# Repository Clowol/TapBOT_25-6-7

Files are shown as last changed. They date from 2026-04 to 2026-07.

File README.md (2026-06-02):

<!--  -->
<div align="center">

# TapSpingRobot-robotArm

</div>

<div align="center">

<span style="font-size:10px;opacity:0.6;">
Open-source implementation for kinematics, control, simulation and modeling of robotic manipulators</br>
</span>

</div>

--- --- ---

<div align="center">

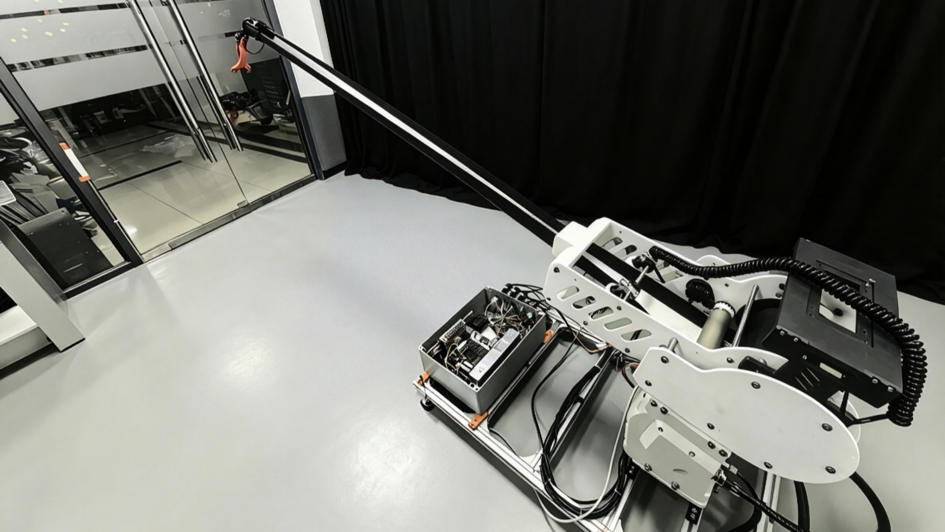
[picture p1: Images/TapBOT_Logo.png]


    
 

</div>
<!-- <p align="center">
<a href="#项目简介">简介</a> •
<a href="#核心功能">功能</a> •
<a href="#项目结构">结构</a> •<a href="#快速开始">快速开始</a> •<a href="#论文成果">论文</a> •<a href="#环境依赖">环境</a></p>
</div> -->

---

## 📖 Project Introduction / 项目简介
This repository contains the complete source code, models, simulation environments and experimental data corresponding to the author’s academic paper and master’s thesis. It focuses on robot arm modeling, motion planning, control algorithms and verification.

<p style="font-size:8px;opacity:0.8;">
本仓库完整收录了作者**小论文**与**硕士学位论文**相关的全部代码、机械臂模型、仿真环境与实验数据，聚焦于机械臂建模、轨迹规划、控制算法与实验验证，同时具备学术价值与工程实用性。
</p>

---

## 🎯 Main Functions / 主要功能
Forward & inverse kinematics, trajectory planning, dynamic modeling, motion control, obstacle avoidance, robot simulation and experimental result visualization.
<p style="font-size:8px;opacity:0.9;">
- 正/逆运动学求解
- 轨迹规划算法实现
- 动力学建模与参数辨识
- 运动控制与优化算法
- 避障与路径规划
- 机器人仿真环境搭建
- 实验曲线与结果可视化
</p>

---

## 📁 Project Structure / 项目结构
'
|--TapROT_26/
| |
| |-- BOM/ 
| |-- Installation Guide
| |-- paper/                 
| |-- Code/
| |-- TapSpingROT_Model/
| |-- TapSpingROT_STL/
| |-- TapSpingROT_URDF/
| |-- README.md
'

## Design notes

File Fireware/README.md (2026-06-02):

```text
--------------------------------------------------------------------
---------------------           科研项目		  -------------------
--------------------------------------------------------------------
```
# 机械臂硬件控制项目

## 1. 项目简介

本项目基于 **STM32F107（Cortex-M3 内核）微控制器**，使用 **Keil uVision（ARMCC）** 作为开发与编译环境，实现一套面向科研与工程验证的 **手动控制（Manual Operation）模式嵌入式系统**。

STM32F107 属于 **Connectivity Line**，片上集成 **CAN / USB OTG / Ethernet / 多路 USART / DMA** 等外设，适合用于：

* 🧪 控制系统与通信协议科研实验
* 🔧 多外设协同控制与实时性验证
* 📚 STM32F1 Connectivity Line 架构学习与工程复现

本仓库已按 **科研级工程规范** 进行整理，适合作为：

* 硕士阶段实验工程仓库
* STM32F107 + Keil 项目模板

-----------------------------------------------------------------------------------------------------

## 2. 硬件与开发环境

| 项目  		| 说明 						|
| ---- 		| --- |
| MCU 		| **STM32F107VC / STM32F107RC（Connectivity Line）** 	|
| 内核  		| ARM Cortex-M3 					|
| 主频 		| 72 MHz 					|
| IDE 		| Keil uVision 5 					|
| 编译器  		| ARMCC / ARM Compiler 							|
| 操作系统 	| Windows  11 							|
| 调试器  		| ST-Link 							|

> ⚠️ **注意**：STM32F107 具有专用启动文件与外设映射，请勿与 F103/F105 混用。

-----------------------------------------------------------------------------------------------------
## 3. 工程目录结构（F107 向科研分层）

```text
MaunalOperation_mode/
├── CMSIS/ # ARM CMSIS 内核与 STM32F107 设备支持
├── FWlib/ # STM32F10x StdPeriph Library（含 F107）
├── Hardware/ # 板级支持包（BSP，强相关硬件）
│ ├── can/ # CAN 通信相关驱动（F107 核心外设）
│ ├── usart/ # 串口通信
│ ├── adc/ # 模拟量采集
│ └── motor/ # 电机/执行器控制
├── System/ # 系统层（时钟/中断/延时/调试接口）
├── User/ # 应用层（控制逻辑 / 状态机）
├── Project/ # Keil 工程文件
│ └── maunaloperation.uvprojx
├── .gitignore # Keil + STM32F107 Git 忽略规则
├── README.md # 项目说明文档
└── keilkill.bat # Keil 临时文件清理脚本（可选）
```

-----------------------------------------------------------------------------------------------------

## 4. 启动文件与系统配置（关键）

### 4.1 启动文件
本工程使用 **STM32F107 专用启动文件**，位于：

```text
CMSIS/DeviceSupport/startup/startup_stm32f10x_cl.s
```

**请确认**：
	* 启动文件为 **Connectivity Line（cl）** 版本
	* 与 MCU 型号（Flash/RAM 大小）匹配

### 4.2 系统时钟配置
	* 外部晶振：8 MHz（常见）
	* 系统主频：72 MHz
	* 时钟初始化位于：
		System/system_stm32f10x.c

	> ⚠️ 修改外部晶振或 PLL 参数时，请同步检查 CAN / USB / Ethernet 时钟配置。

--------------------

## 5. 编译、下载与调试
### 5.1 打开工程

```text
Project/maunaloperation.uvprojx
```

### 5.2 编译
* 编译输出位于：

```text
Objects/
```
> 编译产物 **不纳入 Git 管理**

### 5.3 下载与调试
* 调试接口：SWD / JTAG
* 支持调试器：ST-Link / J-Link

> Debug 相关文件（`.dbgconf`）未纳入版本管理

-----------------------------------------------------------------------------------------------------

## 6. Git 版本管理规范

### 6.1 忽略规则说明

已通过  .gitignore忽略：
* Keil 用户文件：`*.uvoptx` / `*.uvguix.*`
* 编译产物：`Objects/` / `Listings/` / `*.axf` / `*.hex`
* 调试配置：`*.dbgconf`

### 6.2 提交规范（推荐）

```text
feat: 新增外设或功能模块
fix: 修复硬件/驱动问题
exp: 实验性修改
refactor: 结构重构
cleanup: 工程整理（无功能改动）
```

示例：

```bash
git commit -m "feat: add STM32F107 CAN manual control"
```

-----------------------------------------------------------------------------------------------------

## 7. 硬件 使用注意事项

* ⚠️ CAN / USB / Ethernet 需正确配置时钟源
* ⚠️ 不同封装（RC/VC）Flash/RAM 不同
* ⚠️ StdPeriph 库版本需与启动文件一致

-----------------------------------------------------------------------------------------------------

## 9. 作者说明

* 作者：Clomol
* 研究方向：嵌入式系统 / 控制系统 / STM32 通信与驱动

```text
--------------------------------------------------------------------
---------------------           科研项目		  -------------------
--------------------------------------------------------------------
```

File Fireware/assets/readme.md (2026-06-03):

# TapBOT 下位机通讯协议手册

---

## 一、系统控制源

当前有两个控制源：

### 1. 遥控器模式 `RMT_MODE`

- 遥控器从 **USART3** 输入。
- `Rmt_CommProc()` 从 USART3 环形缓冲区解析遥控帧。
- `RmtDataExchange()` 将遥控通道量转换为工程控制量：
  - `RmtGearValue`：M8010 伸缩速度输入，范围约 **-50 ~ +50**
  - `Rmt_Y1_Value`：舵机 1~3 速度输入，范围约 **-50 ~ +50**
  - `Rmt_PTZ_UpDown` / `Rmt_PTZ_LftRgt`：云台方向
  - `RmtClutchStartStop`：电磁阀/离合控制
- `ControlDispatcher_Update()` 将遥控变量整理成统一的 `g_ctrl_cmd`。
- 执行层读取 `g_ctrl_cmd` 控制 M8010、云台、副板舵机。

### 2. 上位机模式 `UP_MODE`

- 上位机从 **USART2** 输入。
- `ROS2_CommProc()` 实际调用 `Upper_CommProc()`。
- `Upper_CommProc()` 解析 **0xA5 自定义协议帧**。
- 解析成功后调用：`ControlDispatcher_OnUpperPacketReceived(cmd_id, payload, len)`

- 控制分配器根据 `cmd_id` 分发到：

| 功能 | 说明 |
|---|---|
| M8010 CAN 控制 | 电机速度/位置控制 |
| 舵机位置控制 | 舵机 1~3 位置闭环 |
| 云台速度/角度控制 | PTZ 控制 |
| 控制源切换/心跳 | 模式切换与保活 |

> **上位机要真正接管，需要满足两个条件：**
>
> 1. 遥控/系统模式变量 `g_RmtUpManCtrlMode == UP_MODE`
> 2. 上位机心跳未超时

上位机超时时间：

```c
CTRL_UPPER_TIMEOUT_TICKS_10MS = 50  // 约 500 ms
```

> **建议**：上位机以 **50~100 ms** 周期发送心跳 `0x7F`。

---

## 二、主循环调度

主循环核心流程：

```c
while(1)
{
    ROS2_CommProc();     // USART2 上位机协议解析
    FunctionProce();     // 遥控、串口、主副板接收处理

    if(flag10ms)   Function_10ms();
    if(cnt30ms)    Function_30ms();
    if(cnt50ms)    Function_50ms();
    if(cnt100ms)   Function_100ms();
    if(cnt500ms)   Function_500ms();
}
```

### 周期任务说明

| 周期 | 函数 | 作用 |
|---|---|---|
| **10ms** | `Function_10ms()` | `ControlDispatcher_Update()` + `SubBoard_LinkTick10ms()` |
| **30ms** | `Function_30ms()` | `YushuMotor_ControlProc()` + M8010 控制输出 |
| **50ms** | `Function_50ms()` | `PTZ_ControlProc()` + `UpperFeedback_SendArmState()` + `UpperFeedback_SendActuatorEcho()` |
| **100ms** | `Function_100ms()` | 仅遥控模式下执行 `Steer_ControlProc()`（避免上位机位置控制时被遥控速度逻辑覆盖） |
| **500ms** | `Function_500ms()` | `UpperFeedback_SendDiag()` |

---

## 三、遥控模式执行逻辑

遥控模式下，控制链路：

```
USART3 遥控器
  -> Rmt_CommProc()
  -> Proce_Rmtdata()
  -> RmtDataExchange()
  -> ControlDispatcher_Update()
  -> g_ctrl_cmd
  -> 执行层
```

### 各执行器行为

**M8010（伸缩电机）：**

- 使用 `RmtGearValue`，中位死区后映射为 `YushuSpeed`
- `YushuSpeed > 0`：电磁阀闭合 `SW_CLUTCH(ON)`
- `YushuSpeed < 0`：电磁阀松开 `SW_CLUTCH(OFF)`
- `YushuSpeed == 0`：发送停止命令

**舵机 1~3：**

- 遥控模式为**速度模式**
- `Rmt_Y1_Value` 映射为 `SteerRunSpeed`
- 通过主副板协议发给副板：`SUBBOARD_CMD_SERVO123_SPEED`

**舵机 4：**

- 不再由主控直接给速度，作为末端自动流程的一部分
- 遥控通道触发自动流程：
  - 按下：`SUBBOARD_CMD_AUTO_START`
  - 松开：`SUBBOARD_CMD_AUTO_STOP`

**云台：**

- 遥控按键触发上下/左右方向
- 使用默认速度：
  - 上下：`PTZ_UP_DOWN_SPEED_DEFAULT = 0x20`
  - 左右：`PTZ_LEFT_RIGHT_SPEED_DEFAULT = 0x10`

---

## 四、上位机到主控板协议

### 物理接口

```
上位机 <-> 主控板 USART2
波特率：115200
```

### 帧格式

```
0xA5  cmd_id  payload_len  payload...  crc_low  crc_high
```

### CRC

```
CRC16-CCITT
init  = 0xFFFF
poly  = 0x1021
计算范围 = cmd_id + payload_len + payload
CRC 低字节先发
```

### 上位机命令 ID

| cmd_id | 名称 | 作用 |
|---|---|---|
| `0x01` | `UPPER_CMD_SET_SOURCE` | 切换控制源 |
| `0x02` | `UPPER_CMD_SET_ALL` | 设置统一控制量 |
| `0x10` | `UPPER_CMD_YUSHU_SPEED` | 设置 M8010 速度目标 |
| `0x11` | `UPPER_CMD_EXEC_YUSHU_CAN` | 直接下发 M8010 CAN 控制量 |
| `0x20` | `UPPER_CMD_STEER_SYNC` | 设置舵机速度型统一命令 |
| `0x21` | `UPPER_CMD_EXEC_STEER_SPEED` | 舵机速度命令（当前不建议作为主路径） |
| `0x22` | `UPPER_CMD_EXEC_STEER_POSITION` | 舵机 1~3 位置控制 |
| `0x23` | `UPPER_CMD_EXEC_STEER_MODE` | 设置舵机默认模式 |
| `0x30` | `UPPER_CMD_PTZ` | 设置云台速度命令到统一控制量 |
| `0x31` | `UPPER_CMD_EXEC_PTZ` | 立即执行云台速度控制 |
| `0x32` | `UPPER_CMD_EXEC_PTZ_ANGLE` | 云台角度闭环目标 |
| `0x7F` | `UPPER_CMD_HEARTBEAT` | 上位机心跳 |

### 推荐上位机接管流程

```
1. 周期发送 0x7F 心跳
2. 发送 0x01，payload = 01，切换到上位机模式
3. 周期发送执行命令
4. 若停止控制，发送速度 0 或停止命令
5. 若失联超过 500ms，主控自动回到遥控模式
```

---

## 五、常用上位机 Payload

### 0x01 SET_SOURCE

```
payload[0] = 0  遥控模式
payload[0] = 1  上位机模式
```

### 0x10 YUSHU_SPEED

```
payload[0..1] = speed_cmd_s16_le    // 实际速度量 = speed_cmd_s16 × 0.1
payload[2]    = clutch_cmd          // 可选: 0=松开, 1=闭合, 0xFF=不改变
```

### 0x11 EXEC_YUSHU_CAN

```
payload[0]   = motor_id
payload[1]   = mode
payload[2:3] = W_s16_le       // W = value × 0.1
payload[4:5] = T_s16_le       // T = value × 0.01
payload[6:7] = K_W_s16_le     // K_W = value × 0.001
```

### 0x22 EXEC_STEER_POSITION（推荐 11 字节格式）

```
payload[0]   = enable_mask          // bit0~bit2 对应舵机1~3
payload[1:2] = pos0_s16_le
payload[3:4] = pos1_s16_le
payload[5:6] = pos2_s16_le
payload[7:8] = run_time_u16_le
payload[9:10] = speed_u16_le
```

> **说明**：当前上位机模式下，舵机 1~3 采用位置控制。舵机 4 不由上位机位置控制，仍归末端自动流程。

### 0x31 EXEC_PTZ

```
payload[0] = up_down_cmd
payload[1] = left_right_cmd
payload[2] = up_down_speed
payload[3] = left_right_speed
```

### 0x32 EXEC_PTZ_ANGLE

```
payload[0:1] = yaw_target_s16_le      // deg × 100
payload[2:3] = pitch_target_s16_le    // deg × 100
payload[4:5] = tolerance_u16_le       // deg × 100
payload[6]   = speed
```

---

## 六、主控板到副板通信

### 物理接口

```
主控板 UART5 <-> 副板 USART1/RS485
波特率：115200
```

### 帧格式

```
0xA6  node_id  cmd_id  payload_len  payload...  crc_low  crc_high
```

当前节点：`node_id = 0x01`

### CRC

```
CRC16-CCITT
init  = 0xFFFF
poly  = 0x1021
计算范围 = node_id + cmd_id + payload_len + payload
CRC 低字节先发
```

### 主控发给副板命令

| cmd_id | 名称 | 作用 |
|---|---|---|
| `0x01` | `HEARTBEAT` | 心跳/查询状态 |
| `0x02` | `ESTOP` | 副板急停 |
| `0x03` | `STOP` | 停止副板动作 |
| `0x04` | `SET_MODE` | 设置副板工作模式 |
| `0x20` | `SERVO123_SPEED` | 舵机 1~3 速度控制 |
| `0x21` | `SERVO123_POSITION` | 舵机 1~3 位置控制 |
| `0x30` | `AUTO_START` | 启动末端自动流程 |
| `0x31` | `AUTO_STOP` | 停止末端自动流程 |
| `0x40` | `PUSHROD` | 预留/推杆控制 |

### 副板反馈

| cmd_id | 名称 | Payload |
|---|---|---|
| `0x80` | `ACK` | state, status, ack_cmd_id |
| `0x81` | `STATE` | state, error |
| `0x83` | `ERROR` | error |

### 副板状态

| 值 | 状态 |
|----|---|
| 0 | `UNKNOWN` |
| 1 | `IDLE` |
| 2 | `REMOTE` |
| 3 | `UPPER` |
| 4 | `AUTO_RUNNING` |
| 5 | `DONE` |
| 6 | `ERROR` |
| 7 | `ESTOP` |

### 副板模式

| 值 | 模式 | 说明 |
|----|---|---|
| 0 | `REMOTE_SPEED` | 遥控速度模式 |
| 1 | `UPPER_POSITION` | 上位机位置模式 |
| 2 | `AUTO` | 自动流程 |
| 3 | `ESTOP` | 急停 |

---

## 七、副板自动流程

副板文件：`end_effector_task.c`

### 自动流程逻辑

```
AUTO_START
  -> 推杆伸出
  -> 保压等待
  -> 舵机4正转
  -> 舵机4反转
  -> 检测光电传感器无物体，或达到反转超时
  -> 舵机4停止
  -> 推杆缩回
  -> DONE
  -> IDLE
```

### 遥控/上位机模式对比

**共同点**：舵机 4 都不直接由外部连续控制，统一归副板自动流程控制。外部只负责触发 `AUTO_START` / `AUTO_STOP`。

| 项目 | 遥控模式 | 上位机模式 |
|---|---|---|
| 舵机 1~3 | 速度模式 | 位置模式 |
| 舵机 4 | 自动流程 | 自动流程 |

---

## 八、主控反馈给上位机

主控通过 USART2 主动反馈，帧格式同上位机协议：

```
0xA5  fb_cmd_id  payload_len  payload...  crc_low  crc_high
```

### 反馈 ID

| fb_cmd_id | 名称 | 周期 |
|---|---|---|
| `0x80` | `ARM_STATE` | 50ms |
| `0x81` | `ACTUATOR_ECHO` | 50ms |
| `0x82` | `DIAG` | 500ms |

### 0x80 ARM_STATE Payload

| 字段 | 类型 | 说明 |
|---|---|---|
| `seq` | u16 | 序列号 |
| `time_ms` | u32 | 时间戳(ms) |
| `ctrl_source` | u8 | 0=遥控, 1=上位机 |
| `system_state` | u8 | 系统状态 |
| `fault_flags` | u16 | 故障标志位 |
| `length_mm` | s32 | M8010 编码器反馈长度 |
| `line_speed_mm` | s16 | 线速度 |
| `limit_switch` | u8 | 限位开关 |
| `clutch_state` | u8 | 离合状态 |
| `servo0_pos` | s16 | 舵机0位置 |
| `servo1_pos` | s16 | 舵机1位置 |
| `servo2_pos` | s16 | 舵机2位置 |
| `servo3_speed` | s16 | 舵机3速度 |
| `yaw_deg_x100` | s16 | 偏航角 ×100 |
| `pitch_deg_x100` | s16 | 俯仰角 ×100 |
| `imu_valid` | u8 | IMU 有效标志 |

### 0x81 ACTUATOR_ECHO Payload

| 字段 | 类型 | 说明 |
|---|---|---|
| `yushu_speed_cmd` | s16 | 速度指令 (×0.1) |
| `cmd_W` | s16 | W 指令 (×0.1) |
| `cmd_T` | s16 | T 指令 (×0.01) |
| `cmd_KW` | s16 | KW 指令 (×0.001) |
| `cmd_mode` | u8 | 指令模式 |
| `servo0_speed` ~ `servo3_speed` | s16 | 舵机 0~3 速度 |
| `ptz_ud_cmd` | u8 | 云台上下指令 |
| `ptz_lr_cmd` | u8 | 云台左右指令 |
| `ptz_ud_speed` | u8 | 云台上下速度 |
| `ptz_lr_speed` | u8 | 云台左右速度 |
| `encoder_valid` | u8 | 编码器有效标志 |
| `steer_actual_mode` | u8 | 舵机实际模式 |
| `ptz_work_status` | u8 | 云台工作状态 |

### 0x82 DIAG Payload

| 字段 | 类型 | 说明 |
|---|---|---|
| `remote_ok` | u8 | 遥控器在线 |
| `upper_alive` | u8 | 上位机在线 |
| `encoder_valid` | u8 | 编码器有效 |
| `imu_valid` | u8 | IMU 有效 |
| `reserved` | u8 | 保留 |
| `limit_switch` | u16 | 限位开关状态 |
| `fault_flags` | u16 | 故障标志位 |

### 故障位 `fault_flags`

| 位 | 含义 |
|----|---|
| bit0 | 上位机心跳超时 |
| bit1 | 遥控器掉线/关机 |
| bit2 | CAN1 通信异常 |
| bit3 | 云台状态异常 |
| bit4 | CAN2/IMU 无效 |

---

## 九、给上位机程序的建议

上位机程序建议分三层写：

```
SerialDriver
  负责串口收发、字节流缓存

TapbotProtocol
  负责 0xA5 帧打包/解析、CRC16-CCITT

ControlNode
  负责业务命令：
  - set_source()
  - heartbeat()
  - set_yushu_speed()
  - set_servo123_position()
  - set_ptz_speed()
  - set_ptz_angle()
  - parse_feedback()
```

### 最小稳定控制周期建议

| 功能 | 建议周期 |
|---|---|
| 心跳 | 50 ~ 100ms |
| 舵机位置控制 | 20 ~ 50ms |
| M8010 速度控制 | 30 ~ 50ms |
| 云台速度控制 | 50ms |
| 反馈解析 | 收到即解析 |

> **特别注意**：上位机进入控制前先发 `0x01 SET_SOURCE = 1`，之后持续发 `0x7F HEARTBEAT`。否则控制分配器会在约 **500ms** 后回退到遥控模式。

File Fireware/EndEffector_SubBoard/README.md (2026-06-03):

# EndEffector_SubBoard

STM32F103 end-effector sub-board framework for the TapBOT arm.

## Hardware role

- RS485 link to STM32F107 main board.
- Photoelectric sensor input.
- Linear pushrod output.
- Four Feetech SMS servos on the end platform.

## Control policy

- Remote mode: servo 1-3 speed commands from main board; servo 4 is reserved for the automatic end-effector workflow.
- Upper-computer mode: servo 1-3 position commands from main board; servo 4 is reserved for the automatic workflow.
- Automatic workflow: object detected, pushrod extends, servo 4 rotates forward, reverses until object clears, pushrod retracts.

## Protocol

Frame: `0xA6 node_id cmd_id payload_len payload crc16_l crc16_h`.
CRC: CRC16-CCITT over `node_id + cmd_id + payload_len + payload`.

Current default pins are placeholders and should be checked against the final PCB:

- USART1 PA9/PA10 for RS485 data.
- PA8 for RS485 DE/RE direction.
- PA0 photoelectric sensor input.
- PB0/PB1 pushrod extend/retract outputs.

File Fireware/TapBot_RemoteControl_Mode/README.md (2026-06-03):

# TapBot Remote Control Mode Firmware

## 1. Overview

This repository contains the STM32F107 firmware for TapBot remote-control mode. The project is based on the STM32F10x Standard Peripheral Library and is built with Keil MDK-ARM.

Current main functions:

- Remote controller control path on USART3.
- Upper-computer / ROS 2 binary protocol on USART2.
- Dynamic control-source arbitration between remote controller and upper computer.
- Unitree M8010 actuator control, with CAN encoder feedback used as the stretch-joint feedback.
- Feetech SMS servo control. Servo ID0-ID2 are position servos; servo ID3 is used as a continuous-rotation speed servo.
- PTZ/gimbal velocity control, with Wit IMU feedback reserved for gimbal closed-loop control.
- Periodic upper-computer feedback frames for state, actuator echo, and diagnostics.

## 2. Build Entry

Keil project:

```text
Project\RemoteControl_Mode.uvprojx
```

Target:

```text
RemoteControl_Mode
```

Toolchain used in recent checks:

```text
D:\Work-tool\Keil_v5\UV4\uVision.com
ARMCC V5.06 update 6
```

Main MCU target:

```text
STM32F107VC
```

## 3. Directory Layout

| Directory | Role |
| --- | --- |
| `App/` | Application entry, scheduler, global configuration and application-level declarations. |
| `App/CPU/` | STM32 interrupt template and standard-library configuration headers. |
| `BSP/` | Board support package: delay, timer, LED, switch GPIO, ADC, encoder, Wit IMU wrapper, low-level system helpers. |
| `Comm/` | Low-level communication drivers: USART, CAN1/CAN2, ring buffer, UART RX driver. |
| `Protocols/` | Protocol layer: remote-controller parser, upper-computer parser, ROS2 wrapper, feedback packing. |
| `Control/` | Control-source dispatcher and common control math. |
| `Actuators/` | Application-level actuator drivers: Feetech SMS servo, PTZ/gimbal, Unitree M8010 wrapper. |
| `Trdlib/GO-M8010-6/` | Third-party Unitree M8010 protocol definitions and helper code. |
| `Trdlib/wit_c_sdk/` | Wit Motion CAN IMU SDK files. |
| `Drivers/CMSIS/` | CMSIS core, STM32F10x device files and startup files. |
| `FWlib/` | STM32F10x Standard Peripheral Library. |
| `Project/` | Keil project, listing, debug configuration and generated build output. |

## 4. Main Runtime Flow

Entry point:

```text
App\main.c
```

Main loop tasks:

```text
Rmt_CommProc();
ROS2_CommProc();
FunctionProce();
```

Periodic scheduler:

```text
App\function.c
```

Typical runtime chain:

```text
USART DMA/IDLE interrupt
-> uart_rx_driver ring buffer
-> protocol parser
-> control_dispatcher
-> actuator drivers
-> periodic feedback to upper computer
```

## 5. Communication Paths

### 5.1 USART2: Upper Computer / ROS 2

Relevant files:

| File | Role |
| --- | --- |
| `Comm/usart.c` | USART2 DMA RX/TX and interrupt handling. |
| `Comm/uart_rx_driver.c` | Per-port RX ring-buffer abstraction. |
| `Protocols/ros2_comm.c` | Thin wrapper calling the upper-computer parser. |
| `Protocols/upper_comm.c` | Parses `0xA5` binary frames and verifies CRC16-CCITT. |
| `Protocols/upper_feedback.c` | Packs feedback frames `0x80`, `0x81`, `0x82`. |
| `Control/control_dispatcher.c` | Dispatches valid upper-computer commands to control or actuator layers. |

Frame format:

```text
0xA5 + CMD_ID + PAYLOAD_LEN + PAYLOAD + CRC_L + CRC_H
```

CRC:

```text
CRC16-CCITT, init 0xFFFF, poly 0x1021
Range: CMD_ID + PAYLOAD_LEN + PAYLOAD
Byte order: low byte first
```

### 5.2 USART3: Remote Controller

Relevant files:

| File | Role |
| --- | --- |
| `Comm/usart.c` | USART3 DMA RX and IDLE interrupt. |
| `Comm/uart_rx_driver.c` | Stores received bytes into the USART3 ring buffer. |
| `Protocols/rmt_comm.c` | Remote frame state machine. |
| `Protocols/rmt_data.c` | Remote data validation, decoding and control variable update. |

The remote path is kept independent from the upper-computer protocol. In remote mode, the dispatcher keeps using remote-controller data as the active command source.

## 6. Source File Summary

### 6.1 App

| File | Role |
| --- | --- |
| `App/main.c` | Hardware initialization and main loop. Initializes USART, CAN, timer, dispatcher, servo mode, PTZ, encoder and IMU. |
| `App/function.c` | Periodic task scheduler and debug helpers. Sends upper-computer feedback periodically. |
| `App/function.h` | Shared application declarations and common includes. |
| `App/app_config.h` | Central project parameters: baud rates, buffer sizes, actuator constants and debug switches. |
| `App/CPU/stm32f10x_conf.h` | Standard Peripheral Library configuration header. |
| `App/CPU/stm32f10x_it.*` | Standard interrupt template; currently not included in the Keil build list. |

### 6.2 BSP

| File | Role |
| --- | --- |
| `BSP/sys.*` | GPIO bit helpers, debug print macros and system helper definitions. |
| `BSP/delay.*` | SysTick-based delay functions. |
| `BSP/timer.*` | Timer initialization and periodic tick counters. |
| `BSP/led.*` | Work/status LED control. |
| `BSP/switch.*` | GPIO switch, limit switch and valve/clutch IO handling. |
| `BSP/encoder.*` | CAN encoder command and feedback parser for the M8010 stretch joint. |
| `BSP/wit_imu.*` | Wit IMU CAN feedback adapter for future gimbal closed-loop control. |
| `BSP/adc.*` | ADC initialization and sampling helpers; present in build but currently not central to the main arm flow. |
| `BSP/board_config.h` | Board-level configuration aliases. |
| `BSP/project_macros.h` | Common macros and print wrappers. |

### 6.3 Comm

| File | Role |
| --- | --- |
| `Comm/usart.*` | USART1/2/3/UART4/UART5 initialization, DMA send/receive and IRQ handlers. |
| `Comm/ring_buf.*` | Generic ring buffer used by UART RX drivers. |
| `Comm/uart_rx_driver.*` | USART2/USART3 receive-buffer management. |
| `Comm/can1.*` | CAN1 initialization, send and receive handling. Used by M8010 and encoder path. |
| `Comm/can2.*` | CAN2 initialization and receive handling. Used by Wit IMU path. |

### 6.4 Protocols

| File | Role |
| --- | --- |
| `Protocols/rmt_comm.*` | Remote-controller frame assembly from USART3 ring buffer. |
| `Protocols/rmt_data.*` | Remote-controller data decoding and remote control variable update. |
| `Protocols/ros2_comm.*` | Upper-computer communication wrapper. |
| `Protocols/upper_comm.*` | USART2 upper-computer frame parser. |
| `Protocols/upper_feedback.*` | STM32-to-upper-computer feedback frame packer. |
| `Protocols/up_data.*` | Legacy upper-layer protocol file. It is still included in the Keil project but is not the current USART2 protocol path. |
| `Protocols/assist_data.*` | Legacy auxiliary-board communication. Not included in the current Keil build. |

### 6.5 Control

| File | Role |
| --- | --- |
| `Control/control_dispatcher.*` | Runtime control-source arbitration and upper-computer command dispatch. |
| `Control/control_math.*` | Shared mapping and control math helpers. |
| `Control/device.*` | Legacy device-control aggregation for engine/generator style modules; not in current Keil build. |
| `Control/lft_engine.*` | Legacy left-engine control logic; not in current Keil build. |
| `Control/rgt_engine.*` | Legacy right-engine control logic; not in current Keil build. |
| `Control/generator.*` | Legacy generator start/stop control logic; not in current Keil build. |

### 6.6 Actuators

| File | Role |
| --- | --- |
| `Actuators/steer_data.*` | Feetech SMS servo driver. Supports SyncWrite, mixed mode, first three position servos and ID3 continuous-rotation speed control. |
| `Actuators/yushu_motor_data.*` | Unitree M8010 command generation and remote/upper-computer speed execution. |
| `Actuators/ptz_data.*` | PTZ/gimbal command packing and control procedure. |

### 6.7 Third-party and Vendor Libraries

| File/Directory | Role |
| --- | --- |
| `Trdlib/GO-M8010-6/` | Unitree M8010 protocol structures and helper implementation. |
| `Trdlib/wit_c_sdk/` | Wit Motion IMU SDK and register definitions. |
| `FWlib/` | STM32F10x Standard Peripheral Library. |
| `Drivers/CMSIS/` | CMSIS core/device/startup files. Current target uses `startup_stm32f10x_cl.s`. |

## 7. Current Upper-computer Feedback

| Feedback ID | Name | Period | Purpose |
| --- | --- | --- | --- |
| `0x80` | `ARM_STATE` | 50 ms | Control source, fault flags, encoder length/speed, servo state, IMU state. |
| `0x81` | `ACTUATOR_ECHO` | 50 ms | Echoes M8010, SMS servo and PTZ commands. |
| `0x82` | `DIAG` | 500 ms | Remote/upper online status and diagnostic flags. |

Protocol documents are stored in:

```text
E:\TapBOT_26\Fireware\assests
```

## 8. Suspected Unused or Legacy Files

The following files are not deleted. They are listed for review before cleanup.

High-confidence legacy candidates:

| File | Reason |
| --- | --- |
| `Protocols/assist_data.c` / `assist_data.h` | Legacy auxiliary-board protocol. Not included in Keil and only references itself. |
| `Control/device.c` / `device.h` | Legacy device aggregator for engine/generator modules. Not included in Keil. |
| `Control/lft_engine.c` / `lft_engine.h` | Legacy left-engine control. Not part of current arm-control flow. |
| `Control/rgt_engine.c` / `rgt_engine.h` | Legacy right-engine control. Not part of current arm-control flow. |
| `Control/generator.c` / `generator.h` | Legacy generator control. Not part of current arm-control flow. |

Review-before-cleanup candidates:

| File | Reason |
| --- | --- |
| `Protocols/up_data.c` / `up_data.h` | Legacy upper-layer protocol. `up_data.c` is still included in Keil, but the active upper-computer protocol is `upper_comm.c` + `upper_feedback.c`. Remove from Keil only after confirming no old symbols are required. |
| `App/CPU/stm32f10x_it.c` / `stm32f10x_it.h` | Interrupt template exists but is not included in the current Keil build. Keep if you plan to move IRQ handlers out of `Comm/usart.c` later. |
| Alternate startup files under `Drivers/CMSIS/Device/` | Only `startup_stm32f10x_cl.s` is used for STM32F107 connectivity line. Other startup files are vendor alternatives for different STM32F1 densities. |

Before deleting anything, confirm which of the above legacy features should be kept for reference.

## 9. Maintenance Notes

- Keep USART2 free of text debug output when the upper-computer binary protocol is enabled. Use `APP_USART2_TEXT_DEBUG` only for temporary debugging.
- Do not place parsing or actuator business logic in USART interrupts. Interrupts should only move bytes into buffers.
- Keep all upper-computer protocol payloads at or below `UPPER_PAYLOAD_MAX_LEN`.
- For M8010 closed-loop control, use encoder feedback from `BSP/encoder.c`, not only the sent speed command.
- For PTZ angle closed-loop control, first check `imu_valid` in feedback.
- The SMS servo path follows the Feetech SMS protocol internally. Multi-byte values are little-endian.

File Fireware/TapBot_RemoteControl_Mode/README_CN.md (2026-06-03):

# TapBot 遥控模式固件维护说明

## 1. 工程概述

本工程是 TapBot 机械臂遥控模式下的 STM32F107 固件，基于 STM32F10x 标准外设库，使用 Keil MDK-ARM 编译。

当前主要功能：

- USART3 遥控器控制链路。
- USART2 上位机 / ROS 2 二进制通讯协议。
- 遥控器与上位机双控制源动态切换。
- 宇树 M8010 电机控制，伸缩关节实际反馈来自 CAN 编码器。
- 飞特 SMS 系列舵机控制。ID0-ID2 作为位置舵机，ID3 作为连续旋转速度舵机。
- 云台速度控制，预留维特 IMU 反馈用于云台闭环。
- 周期性向上位机反馈机械臂状态、执行器回显和诊断信息。

## 2. 编译入口

Keil 工程文件：

```text
Project\RemoteControl_Mode.uvprojx
```

目标 Target：

```text
RemoteControl_Mode
```

最近使用的工具链：

```text
D:\Work-tool\Keil_v5\UV4\uVision.com
ARMCC V5.06 update 6
```

芯片型号：

```text
STM32F107VC
```

## 3. 目录结构

| 目录 | 作用 |
| --- | --- |
| `App/` | 应用入口、周期调度、全局配置和应用层声明。 |
| `App/CPU/` | STM32 中断模板和标准库配置头文件。 |
| `BSP/` | 板级支持包：延时、定时器、LED、开关量、ADC、编码器、Wit IMU适配、系统辅助函数。 |
| `Comm/` | 通讯驱动：USART、CAN1/CAN2、环形缓冲区、串口接收驱动。 |
| `Protocols/` | 协议层：遥控器解析、上位机解析、ROS2包装、反馈打包。 |
| `Control/` | 控制源分配器和通用控制数学函数。 |
| `Actuators/` | 执行器应用层驱动：飞特 SMS 舵机、云台、宇树 M8010。 |
| `Trdlib/GO-M8010-6/` | 宇树 M8010 第三方协议定义和辅助代码。 |
| `Trdlib/wit_c_sdk/` | 维特 CAN IMU SDK 文件。 |
| `Drivers/CMSIS/` | CMSIS Core、STM32F10x 设备文件和启动文件。 |
| `FWlib/` | STM32F10x 标准外设库。 |
| `Project/` | Keil 工程、列表文件、调试配置和构建输出。 |

## 4. 主运行流程

入口文件：

```text
App\main.c
```

主循环中主要调用：

```text
Rmt_CommProc();
ROS2_CommProc();
FunctionProce();
```

周期调度文件：

```text
App\function.c
```

典型链路：

```text
USART DMA/IDLE 中断
-> uart_rx_driver 环形缓冲区
-> 协议解析
-> control_dispatcher 控制分配
-> 执行器驱动
-> 周期反馈到上位机
```

## 5. 通讯链路

### 5.1 USART2：上位机 / ROS 2

| 文件 | 作用 |
| --- | --- |
| `Comm/usart.c` | USART2 DMA 收发和中断处理。 |
| `Comm/uart_rx_driver.c` | 按端口管理串口接收环形缓冲区。 |
| `Protocols/ros2_comm.c` | ROS2/上位机通讯包装层。 |
| `Protocols/upper_comm.c` | 解析 `0xA5` 二进制帧并校验 CRC16-CCITT。 |
| `Protocols/upper_feedback.c` | 打包反馈帧 `0x80`、`0x81`、`0x82`。 |
| `Control/control_dispatcher.c` | 将有效上位机命令分发到控制层或执行器层。 |

上位机帧格式：

```text
0xA5 + CMD_ID + PAYLOAD_LEN + PAYLOAD + CRC_L + CRC_H
```

CRC：

```text
CRC16-CCITT，初值 0xFFFF，多项式 0x1021
范围：CMD_ID + PAYLOAD_LEN + PAYLOAD
字节序：低字节在前
```

### 5.2 USART3：遥控器

| 文件 | 作用 |
| --- | --- |
| `Comm/usart.c` | USART3 DMA 接收和 IDLE 中断。 |
| `Comm/uart_rx_driver.c` | 将接收字节写入 USART3 环形缓冲区。 |
| `Protocols/rmt_comm.c` | 遥控器帧状态机组帧。 |
| `Protocols/rmt_data.c` | 遥控器数据校验、解析和控制量更新。 |

遥控器链路与上位机链路相互独立。遥控模式下，控制分配器继续使用遥控器数据作为有效控制源。

## 6. 源文件作用归纳

### 6.1 App

| 文件 | 作用 |
| --- | --- |
| `App/main.c` | 硬件初始化和主循环。初始化 USART、CAN、定时器、控制分配器、舵机默认模式、云台、编码器和 IMU。 |
| `App/function.c` | 周期任务调度和调试辅助函数，周期发送上位机反馈。 |
| `App/function.h` | 应用层共享声明和公共 include。 |
| `App/app_config.h` | 工程核心参数：波特率、缓冲区大小、执行器常量、调试开关等。 |
| `App/CPU/stm32f10x_conf.h` | 标准外设库配置头文件。 |
| `App/CPU/stm32f10x_it.*` | 标准中断模板；当前未加入 Keil 编译列表。 |

### 6.2 BSP

| 文件 | 作用 |
| --- | --- |
| `BSP/sys.*` | GPIO 位操作、调试打印宏和系统辅助定义。 |
| `BSP/delay.*` | 基于 SysTick 的延时函数。 |
| `BSP/timer.*` | 定时器初始化和周期计数。 |
| `BSP/led.*` | 工作状态 LED 控制。 |
| `BSP/switch.*` | 开关量、限位开关、电磁阀/离合 IO 控制。 |
| `BSP/encoder.*` | M8010 伸缩关节 CAN 编码器命令和反馈解析。 |
| `BSP/wit_imu.*` | 维特 IMU CAN 反馈适配，用于后续云台闭环。 |
| `BSP/adc.*` | ADC 初始化和采样辅助；当前不是机械臂主流程核心。 |
| `BSP/board_config.h` | 板级配置别名。 |
| `BSP/project_macros.h` | 通用宏和打印包装。 |

### 6.3 Comm

| 文件 | 作用 |
| --- | --- |
| `Comm/usart.*` | USART1/2/3/UART4/UART5 初始化、DMA 收发和中断处理。 |
| `Comm/ring_buf.*` | 通用环形缓冲区。 |
| `Comm/uart_rx_driver.*` | USART2/USART3 接收缓冲区管理。 |
| `Comm/can1.*` | CAN1 初始化、发送和接收处理。用于 M8010 与编码器链路。 |
| `Comm/can2.*` | CAN2 初始化和接收处理。用于 Wit IMU 链路。 |

### 6.4 Protocols

| 文件 | 作用 |
| --- | --- |
| `Protocols/rmt_comm.*` | 从 USART3 环形缓冲区组装遥控器数据帧。 |
| `Protocols/rmt_data.*` | 遥控器数据解析和遥控控制变量更新。 |
| `Protocols/ros2_comm.*` | 上位机通讯包装。 |
| `Protocols/upper_comm.*` | USART2 上位机协议解析。 |
| `Protocols/upper_feedback.*` | STM32 到上位机的反馈帧打包。 |
| `Protocols/up_data.*` | 旧上层协议文件。当前上位机主链路不是它，但 `up_data.c` 仍在 Keil 工程中。 |
| `Protocols/assist_data.*` | 旧辅助板通讯协议。当前未加入 Keil 编译。 |

### 6.5 Control

| 文件 | 作用 |
| --- | --- |
| `Control/control_dispatcher.*` | 运行时控制源仲裁和上位机命令分发。 |
| `Control/control_math.*` | 控制映射和通用数学辅助函数。 |
| `Control/device.*` | 旧设备控制聚合模块，服务发动机/发电机类模块；当前未加入 Keil 编译。 |
| `Control/lft_engine.*` | 旧左发动机控制逻辑；当前不属于机械臂主流程。 |
| `Control/rgt_engine.*` | 旧右发动机控制逻辑；当前不属于机械臂主流程。 |
| `Control/generator.*` | 旧发电机启停控制逻辑；当前不属于机械臂主流程。 |

### 6.6 Actuators

| 文件 | 作用 |
| --- | --- |
| `Actuators/steer_data.*` | 飞特 SMS 舵机驱动。支持 SyncWrite、混合模式、前三个位置舵机和 ID3 连续旋转速度控制。 |
| `Actuators/yushu_motor_data.*` | 宇树 M8010 命令生成和遥控/上位机速度执行。 |
| `Actuators/ptz_data.*` | 云台命令封装和控制过程。 |

### 6.7 第三方与官方库

| 文件/目录 | 作用 |
| --- | --- |
| `Trdlib/GO-M8010-6/` | 宇树 M8010 协议结构和辅助实现。 |
| `Trdlib/wit_c_sdk/` | 维特 IMU SDK 和寄存器定义。 |
| `FWlib/` | STM32F10x 标准外设库。 |
| `Drivers/CMSIS/` | CMSIS Core、设备文件和启动文件。当前目标使用 `startup_stm32f10x_cl.s`。 |

## 7. 当前上位机反馈

| 反馈 ID | 名称 | 周期 | 作用 |
| --- | --- | --- | --- |
| `0x80` | `ARM_STATE` | 50 ms | 控制源、故障标志、编码器长度/速度、舵机状态、IMU 状态。 |
| `0x81` | `ACTUATOR_ECHO` | 50 ms | 回显 M8010、SMS 舵机和云台命令。 |
| `0x82` | `DIAG` | 500 ms | 遥控器/上位机在线状态和诊断标志。 |

协议文档保存位置：

```text
E:\TapBOT_26\Fireware\assests
```

## 8. 疑似无用或历史遗留文件

以下文件暂未删除，仅列为待你确认的清理候选。

高置信历史遗留候选：

| 文件 | 原因 |
| --- | --- |
| `Protocols/assist_data.c` / `assist_data.h` | 旧辅助板通讯协议，未加入 Keil，引用关系基本只在自身内部。 |
| `Control/device.c` / `device.h` | 旧设备控制聚合模块，服务发动机/发电机链路，未加入 Keil。 |
| `Control/lft_engine.c` / `lft_engine.h` | 旧左发动机控制逻辑，不属于当前机械臂主链路。 |
| `Control/rgt_engine.c` / `rgt_engine.h` | 旧右发动机控制逻辑，不属于当前机械臂主链路。 |
| `Control/generator.c` / `generator.h` | 旧发电机控制逻辑，不属于当前机械臂主链路。 |

需要谨慎确认的候选：

| 文件 | 原因 |
| --- | --- |
| `Protocols/up_data.c` / `up_data.h` | 旧上层协议。`up_data.c` 仍在 Keil 工程中，但当前有效上位机协议是 `upper_comm.c` + `upper_feedback.c`。确认没有旧符号依赖后，可考虑从 Keil 移除。 |
| `App/CPU/stm32f10x_it.c` / `stm32f10x_it.h` | 标准中断模板存在，但当前未加入 Keil。若以后要把中断集中迁回 `stm32f10x_it.c`，则应保留。 |
| `Drivers/CMSIS/Device/` 下其他 startup 文件 | 当前 STM32F107 使用 `startup_stm32f10x_cl.s`。其他启动文件是不同容量/系列的 CMSIS 备选文件，可保留作官方库参考。 |

删除前请确认：是否还需要保留旧发动机/发电机/辅助板协议作为历史参考或未来迁移素材。

## 9. 维护注意事项

- USART2 承载上位机二进制协议，正常运行时不要输出文本调试信息。临时调试请使用 `APP_USART2_TEXT_DEBUG`。
- USART 中断中只做字节搬运，不放协议解析和执行器业务逻辑。
- 上位机 payload 长度不要超过 `UPPER_PAYLOAD_MAX_LEN`。
- M8010 闭环控制应使用 `BSP/encoder.c` 的编码器反馈，而不是只看发送出去的速度命令。
- 云台角度闭环前，应先检查反馈中的 `imu_valid`。
- SMS 舵机底层仍遵循飞特 SMS 协议，多字节字段低字节在前。

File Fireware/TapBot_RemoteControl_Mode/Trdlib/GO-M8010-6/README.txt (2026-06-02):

---------   Part1： code   ----------
         hal库的底层通信头文件
---------     代码文件说明 ----------

usart.h			底层通信头文件
motor_control.h	电机通信头文件
crc_ccitt.h  		CRC校核头文件

ris_protocol.h		电机通信指令集

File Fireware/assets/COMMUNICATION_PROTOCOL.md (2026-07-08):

# TapBot Lower-Level Communication Protocol

This document describes the current firmware protocol between:

- Main board and ROS2 upper computer
- Main board and end-effector sub-board

All multi-byte numeric fields are little-endian unless otherwise noted.

## 1. Main Board <-> ROS2 Upper Computer

Physical link: USART2, 115200 baud.

Frame format:

| Byte | Field |
|---:|---|
| 0 | `0xA5` frame header |
| 1 | `cmd_id` |
| 2 | `payload_len` |
| 3..N | payload |
| N+1 | `crc_low` |
| N+2 | `crc_high` |

CRC: CRC16-CCITT, initial value `0xFFFF`, polynomial `0x1021`.

CRC input range:

```text
cmd_id + payload_len + payload
```

The frame header `0xA5` is not included in CRC.

Maximum payload length: 32 bytes.

### 1.1 Upper Computer Commands

| ID | Name | Payload |
|---:|---|---|
| `0x01` | `SET_SOURCE` | `u8 source`; `0=remote`, `1=upper` |
| `0x02` | `SET_ALL` | `s16 yushu_speed_x10`, `s16 steer_axis_x10`, `u8 steer_enable_mask`, `u8 ptz_ud_cmd`, `u8 ptz_lr_cmd`, `u8 ptz_ud_speed`, `u8 ptz_lr_speed`, optional `u8 clutch_cmd` |
| `0x10` | `YUSHU_SPEED` | `s16 speed_x10`, optional `u8 clutch_cmd` |
| `0x11` | `EXEC_YUSHU_CAN` | `u8 id`, `u8 mode`, `s16 W_x10`, `s16 T_x100`, `s16 K_W_x1000` |
| `0x12` | `YUSHU_LENGTH` | `s32 target_length_mm`, optional `u16 max_speed_x10` |
| `0x20` | `STEER_SYNC` | `s16 steer_axis_x10`, `u8 enable_mask` |
| `0x21` | `EXEC_STEER_SPEED` | Format A: `u8 enable_mask`, `s16 speed0`, `s16 speed1`, `s16 speed2`, `s16 speed3`; Format B: `u8 enable`, `s16 rotate_speed` |
| `0x22` | `EXEC_STEER_POSITION` | `u8 enable_mask`, `s16 pos0`, `s16 pos1`, `s16 pos2`, optional `s16 pos3`, `u16 run_time`, `u16 speed` |
| `0x23` | `EXEC_STEER_MODE` | `u8 mode`; current firmware sets the default mixed mode |
| `0x30` | `PTZ` | `u8 up_down_cmd`, `u8 left_right_cmd`, `u8 up_down_speed`, `u8 left_right_speed` |
| `0x31` | `EXEC_PTZ` | Same as `PTZ`; immediate execution |
| `0x32` | `EXEC_PTZ_ANGLE` | `s16 yaw_deg_x100`, `s16 pitch_deg_x100`, `u16 tolerance_x100`, `u8 speed` |
| `0x7F` | `HEARTBEAT` | Empty payload |

PTZ direction values:

| Value | Meaning |
|---:|---|
| `0` | stop |
| `1` | up |
| `2` | down |
| `3` | left |
| `4` | right |

Control source values:

| Value | Meaning |
|---:|---|
| `0` | remote controller |
| `1` | upper computer |

Upper-computer watchdog timeout: 50 ticks at 10 ms, approximately 500 ms.

### 1.2 Main Board Feedback

Feedback frame uses the same `0xA5` frame format and CRC rule.

| ID | Name | Nominal period | Payload |
|---:|---|---|---|
| `0x80` | `ARM_STATE` | 100 ms | `u16 seq`, `u32 time_ms`, `u8 active_source`, `u8 system_state`, `u16 fault_flags`, `s32 length_mm`, `s16 line_speed_mm_s`, `u8 limit_switch`, `u8 clutch_state`, `s16 servo_pos0`, `s16 servo_pos1`, `s16 servo_pos2`, `s16 rotate_servo_speed`, `s16 imu_yaw_x100`, `s16 imu_pitch_x100`, `u8 imu_valid` |
| `0x81` | `ACTUATOR_ECHO` | 100 ms | `s16 yushu_speed_x10`, `s16 cmd_W_x10`, `s16 cmd_T_x100`, `s16 cmd_KW_x1000`, `u8 motor_mode`, `s16 steer_speed0`, `s16 steer_speed1`, `s16 steer_speed2`, `s16 steer_speed3`, `u8 ptz_ud_cmd`, `u8 ptz_lr_cmd`, `u8 ptz_ud_speed`, `u8 ptz_lr_speed`, `u8 encoder_valid`, `u8 steer_mode`, `u8 ptz_status` |
| `0x82` | `DIAG` | 500 ms, sent through the 50 ms feedback scheduler | `u8 rmt_online`, `u8 upper_online`, `u8 encoder_valid`, `u8 imu_valid`, `u8 reserved`, `u16 limit_switch`, `u16 fault_flags` |

Fault flags:

| Bit | Meaning |
|---:|---|
| 0 | upper computer timeout |
| 1 | remote controller power-off or communication timeout |
| 2 | CAN1 / encoder communication timeout |
| 3 | PTZ status error |
| 4 | CAN2 / IMU timeout or IMU invalid |

## 2. Main Board <-> End-Effector Sub-Board

Physical link: UART5 / RS485, 115200 baud.

Frame format:

| Byte | Field |
|---:|---|
| 0 | `0xA6` frame header |
| 1 | `node_id`, currently `0x01` |
| 2 | `cmd_id` |
| 3 | `payload_len` |
| 4..N | payload |
| N+1 | `crc_low` |
| N+2 | `crc_high` |

CRC: CRC16-CCITT, initial value `0xFFFF`, polynomial `0x1021`.

CRC input range:

```text
node_id + cmd_id + payload_len + payload
```

The frame header `0xA6` is not included in CRC.

Maximum payload length: 32 bytes.

### 2.1 Main Board Commands To Sub-Board

| ID | Name | Payload |
|---:|---|---|
| `0x01` | `HEARTBEAT` | Empty |
| `0x02` | `ESTOP` | Empty |
| `0x03` | `STOP` | Empty |
| `0x04` | `SET_MODE` | `u8 mode` |
| `0x20` | `SERVO123_SPEED` | `s16 speed0`, `s16 speed1`, `s16 speed2` |
| `0x21` | `SERVO123_POSITION` | `s16 pos0`, `s16 pos1`, `s16 pos2`, `u16 run_time`, `u16 speed` |
| `0x30` | `AUTO_START` | `u16 forward_ms`, `u16 reverse_ms`, `s16 speed` |
| `0x31` | `AUTO_STOP` | Empty |
| `0x40` | `PUSHROD` | Defined but not currently packed by the main-board sender |

Sub-board mode values:

| Value | Meaning |
|---:|---|
| `0` | remote speed mode |
| `1` | upper position mode |
| `2` | automatic task mode |
| `3` | emergency-stop mode |

### 2.2 Sub-Board Feedback To Main Board

| ID | Name | Payload |
|---:|---|---|
| `0x80` | `ACK` | `u8 state`, `u8 status`, `u8 ack_cmd_id` |
| `0x81` | `STATE` | `u8 state`, `u8 error` |
| `0x82` | `SERVO` | Defined; currently not parsed by the main board |
| `0x83` | `ERROR` | `u8 error` |

Sub-board state values:

| Value | Meaning |
|---:|---|
| `0` | unknown |
| `1` | idle |
| `2` | remote |
| `3` | upper |
| `4` | auto running |
| `5` | done |
| `6` | error |
| `7` | emergency stop |

Sub-board error values:

| Value | Meaning |
|---:|---|
| `0` | none |
| `1` | CRC error |
| `2` | length error |
| `3` | timeout |
| `4` | sensor error |
| `5` | pushrod error |
| `6` | servo error |

The main board stores the latest sub-board ACK command ID through `SubBoard_LinkGetLastAckCmd()`.

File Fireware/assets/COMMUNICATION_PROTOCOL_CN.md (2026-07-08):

# TapBot 下位机通信协议说明

本文档面向 ROS2 上位机与下位机联调开发，整理当前固件中的两条通信链路：

- 主控板 <-> ROS2 上位机
- 主控板 <-> 末端副板

除特别说明外，所有多字节数据均采用小端格式，即低字节在前。

## 1. 基本数据类型

| 类型 | 长度 | 说明 |
|---|---:|---|
| `u8` | 1 byte | 无符号 8 位整数 |
| `s16` | 2 bytes | 有符号 16 位整数，小端 |
| `u16` | 2 bytes | 无符号 16 位整数，小端 |
| `s32` | 4 bytes | 有符号 32 位整数，小端 |
| `u32` | 4 bytes | 无符号 32 位整数，小端 |

常用缩放规则：

| 后缀 | 含义 | 示例 |
|---|---|---|
| `_x10` | 实际值乘以 10 后发送 | `123` 表示 `12.3` |
| `_x100` | 实际值乘以 100 后发送 | `9000` 表示 `90.00 deg` |
| `_x1000` | 实际值乘以 1000 后发送 | `50` 表示 `0.050` |

## 2. 主控板 <-> ROS2 上位机

### 2.1 串口参数

| 项目 | 参数 |
|---|---|
| 接口 | USART2 |
| 波特率 | 115200 |
| 数据位 | 8 |
| 停止位 | 1 |
| 校验 | 无 |
| 最大 payload | 32 bytes |

### 2.2 帧格式

```text
+--------+--------+-------------+----------+----------+----------+
| 0xA5   | cmd_id | payload_len | payload  | crc_low  | crc_high |
+--------+--------+-------------+----------+----------+----------+
  1 byte   1 byte    1 byte       N bytes    1 byte     1 byte
```

字段说明：

| 字段 | 说明 |
|---|---|
| `0xA5` | 固定帧头 |
| `cmd_id` | 命令或反馈 ID |
| `payload_len` | payload 长度，范围 `0~32` |
| `payload` | 数据区 |
| `crc_low/crc_high` | CRC16-CCITT，小端 |

CRC 规则：

| 项目 | 参数 |
|---|---|
| 算法 | CRC16-CCITT |
| 初值 | `0xFFFF` |
| 多项式 | `0x1021` |
| 覆盖范围 | `cmd_id + payload_len + payload` |
| 是否包含帧头 | 不包含 |

### 2.3 上位机控制源

控制源枚举：

| 值 | 含义 |
|---:|---|
| `0` | 遥控器控制 |
| `1` | ROS2 上位机控制 |

上位机有效超时约为 `500 ms`。超过超时时间未收到有效上位机数据，主控板会回退到遥控模式，并对云台发送停止命令。

### 2.4 上位机 -> 主控板命令

#### `0x01 SET_SOURCE`

切换控制源。

Payload：

| Offset | 类型 | 字段 | 说明 |
|---:|---|---|---|
| 0 | `u8` | `source` | `0=遥控器`，`1=上位机` |

#### `0x02 SET_ALL`

综合控制命令。用于一次性下发钢带速度、末端舵机速度轴、云台速度方向等。

Payload：

| Offset | 类型 | 字段 | 说明 |
|---:|---|---|---|
| 0 | `s16` | `yushu_speed_x10` | 钢带速度命令，实际值 = 该值 / 10 |
| 2 | `s16` | `steer_axis_x10` | 末端三舵机遥控速度轴，实际值 = 该值 / 10 |
| 4 | `u8` | `steer_enable_mask` | bit0~bit3 对应舵机 0~3 使能 |
| 5 | `u8` | `ptz_ud_cmd` | 云台上下方向 |
| 6 | `u8` | `ptz_lr_cmd` | 云台左右方向 |
| 7 | `u8` | `ptz_ud_speed` | 云台上下速度 |
| 8 | `u8` | `ptz_lr_speed` | 云台左右速度 |
| 9 | `u8` | `clutch_cmd` | 可选，`0=断开`，`1=吸合`，未提供则无效 |

说明：该命令会退出钢带长度闭环，转为速度控制。

#### `0x10 YUSHU_SPEED`

钢带伸缩速度控制。

Payload：

| Offset | 类型 | 字段 | 说明 |
|---:|---|---|---|
| 0 | `s16` | `speed_x10` | 速度命令，实际值 = 该值 / 10 |
| 2 | `u8` | `clutch_cmd` | 可选，`0=断开`，`1=吸合` |

说明：该命令会退出钢带长度闭环。

#### `0x12 YUSHU_LENGTH`

钢带长度闭环控制。下位机使用编码器反馈进行 PID 闭环。

Payload：

| Offset | 类型 | 字段 | 说明 |
|---:|---|---|---|
| 0 | `s32` | `target_length_mm` | 目标长度，单位 mm |
| 4 | `u16` | `max_speed_x10` | 可选，最大速度，实际值 = 该值 / 10 |

如果未提供 `max_speed_x10`，下位机使用默认最大速度。

#### `0x11 EXEC_YUSHU_CAN`

底层玉树电机直通控制命令。当前工程配置下玉树电机主要走 USART1，CAN 直通用于兼容。

Payload：

| Offset | 类型 | 字段 | 说明 |
|---:|---|---|---|
| 0 | `u8` | `id` | 电机 ID |
| 1 | `u8` | `mode` | 电机模式 |
| 2 | `s16` | `W_x10` | 速度，实际值 = 该值 / 10 |
| 4 | `s16` | `T_x100` | 力矩，实际值 = 该值 / 100 |
| 6 | `s16` | `K_W_x1000` | 速度刚度，实际值 = 该值 / 1000 |

#### `0x20 STEER_SYNC`

末端舵机速度轴控制，适合连续控制。

Payload：

| Offset | 类型 | 字段 | 说明 |
|---:|---|---|---|
| 0 | `s16` | `steer_axis_x10` | 速度轴命令，实际值 = 该值 / 10 |
| 2 | `u8` | `enable_mask` | bit0~bit3 对应舵机 0~3 使能 |

#### `0x21 EXEC_STEER_SPEED`

末端旋转舵机速度直控。

格式 A：

| Offset | 类型 | 字段 | 说明 |
|---:|---|---|---|
| 0 | `u8` | `enable_mask` | bit3 有效时读取旋转舵机速度 |
| 1 | `s16` | `speed0` | 舵机 0 速度 |
| 3 | `s16` | `speed1` | 舵机 1 速度 |
| 5 | `s16` | `speed2` | 舵机 2 速度 |
| 7 | `s16` | `speed3` | 舵机 3 速度 |

格式 B：

| Offset | 类型 | 字段 | 说明 |
|---:|---|---|---|
| 0 | `u8` | `enable` | 非 0 时启用 |
| 1 | `s16` | `rotate_speed` | 旋转舵机速度 |

#### `0x22 EXEC_STEER_POSITION`

末端三个位置舵机位置控制。

Payload：

| Offset | 类型 | 字段 | 说明 |
|---:|---|---|---|
| 0 | `u8` | `enable_mask` | bit0~bit2 对应三个位置舵机 |
| 1 | `s16` | `pos0` | 舵机 0 目标位置 |
| 3 | `s16` | `pos1` | 舵机 1 目标位置 |
| 5 | `s16` | `pos2` | 舵机 2 目标位置 |
| 7 | `s16` | `pos3` | 可选，兼容字段 |
| 9 或 7 | `u16` | `run_time` | 运行时间 |
| 11 或 9 | `u16` | `speed` | 运行速度 |

说明：

- 当 payload 长度 >= 13 时，包含 `pos3`，`run_time` 从 offset 9 开始。
- 当 payload 长度 >= 11 且 < 13 时，不含 `pos3`，`run_time` 从 offset 7 开始。

#### `0x23 EXEC_STEER_MODE`

末端舵机模式设置。当前主板实现会设置为默认混合模式。

Payload：

| Offset | 类型 | 字段 | 说明 |
|---:|---|---|---|
| 0 | `u8` | `mode` | 当前未进一步区分，仅触发默认模式 |

#### `0x30 PTZ`

云台速度控制命令，进入周期控制流程。

Payload：

| Offset | 类型 | 字段 | 说明 |
|---:|---|---|---|
| 0 | `u8` | `up_down_cmd` | 上下方向 |
| 1 | `u8` | `left_right_cmd` | 左右方向 |
| 2 | `u8` | `up_down_speed` | 上下速度 |
| 3 | `u8` | `left_right_speed` | 左右速度 |

方向枚举：

| 值 | 含义 |
|---:|---|
| `0` | 停止 |
| `1` | 上 |
| `2` | 下 |
| `3` | 左 |
| `4` | 右 |

#### `0x31 EXEC_PTZ`

云台速度控制命令，立即执行并发送云台控制帧。

Payload 同 `0x30 PTZ`。

#### `0x32 EXEC_PTZ_ANGLE`

云台角度闭环控制。下位机结合 IMU yaw/pitch 反馈进行 PID 控制。

Payload：

| Offset | 类型 | 字段 | 说明 |
|---:|---|---|---|
| 0 | `s16` | `yaw_deg_x100` | 目标 yaw，单位 deg x100 |
| 2 | `s16` | `pitch_deg_x100` | 目标 pitch，单位 deg x100 |
| 4 | `u16` | `tolerance_x100` | 角度容差，单位 deg x100 |
| 6 | `u8` | `speed` | 最大速度，0 表示使用默认值 |

#### `0x7F HEARTBEAT`

上位机心跳。

Payload：空。

### 2.5 主控板 -> 上位机反馈

主控板反馈使用同一 `0xA5` 帧格式。

#### `0x80 ARM_STATE`

周期：约 100 ms。

Payload：

| Offset | 类型 | 字段 | 说明 |
|---:|---|---|---|
| 0 | `u16` | `seq` | 反馈序号 |
| 2 | `u32` | `time_ms` | 下位机反馈时间戳 |
| 6 | `u8` | `active_source` | 当前实际控制源 |
| 7 | `u8` | `system_state` | 系统状态，当前固定为 0 |
| 8 | `u16` | `fault_flags` | 故障标志位 |
| 10 | `s32` | `length_mm` | 钢带编码器长度，单位 mm |
| 14 | `s16` | `line_speed_mm_s` | 钢带线速度，单位 mm/s |
| 16 | `u8` | `limit_switch` | 限位开关状态 |
| 17 | `u8` | `clutch_state` | 离合器输出状态 |
| 18 | `s16` | `servo_pos0` | 舵机 0 目标/缓存位置 |
| 20 | `s16` | `servo_pos1` | 舵机 1 目标/缓存位置 |
| 22 | `s16` | `servo_pos2` | 舵机 2 目标/缓存位置 |
| 24 | `s16` | `rotate_servo_speed` | 旋转舵机速度 |
| 26 | `s16` | `imu_yaw_x100` | IMU yaw |
| 28 | `s16` | `imu_pitch_x100` | IMU pitch |
| 30 | `u8` | `imu_valid` | IMU 有效标志 |

#### `0x81 ACTUATOR_ECHO`

周期：约 100 ms。

Payload：

| Offset | 类型 | 字段 | 说明 |
|---:|---|---|---|
| 0 | `s16` | `yushu_speed_x10` | 当前钢带速度命令 |
| 2 | `s16` | `cmd_W_x10` | 电机底层 W |
| 4 | `s16` | `cmd_T_x100` | 电机底层 T |
| 6 | `s16` | `cmd_KW_x1000` | 电机底层 K_W |
| 8 | `u8` | `motor_mode` | 电机模式 |
| 9 | `s16` | `steer_speed0` | 舵机 0 速度 |
| 11 | `s16` | `steer_speed1` | 舵机 1 速度 |
| 13 | `s16` | `steer_speed2` | 舵机 2 速度 |
| 15 | `s16` | `steer_speed3` | 舵机 3 速度 |
| 17 | `u8` | `ptz_ud_cmd` | 云台上下方向 |
| 18 | `u8` | `ptz_lr_cmd` | 云台左右方向 |
| 19 | `u8` | `ptz_ud_speed` | 云台上下速度 |
| 20 | `u8` | `ptz_lr_speed` | 云台左右速度 |
| 21 | `u8` | `encoder_valid` | 编码器有效标志 |
| 22 | `u8` | `steer_mode` | 末端舵机模式 |
| 23 | `u8` | `ptz_status` | 云台状态 |

#### `0x82 DIAG`

周期：约 500 ms。  
该帧通过 50 ms 反馈调度槽发送，避免 USART2 DMA 帧互相覆盖。

Payload：

| Offset | 类型 | 字段 | 说明 |
|---:|---|---|---|
| 0 | `u8` | `rmt_online` | 遥控器在线 |
| 1 | `u8` | `upper_online` | 上位机在线 |
| 2 | `u8` | `encoder_valid` | 编码器有效 |
| 3 | `u8` | `imu_valid` | IMU 有效 |
| 4 | `u8` | `reserved` | 保留 |
| 5 | `u16` | `limit_switch` | 限位开关状态 |
| 7 | `u16` | `fault_flags` | 故障标志 |

故障标志：

| Bit | 含义 |
|---:|---|
| 0 | 上位机通信超时 |
| 1 | 遥控器掉电或通信超时 |
| 2 | CAN1 / 编码器通信超时 |
| 3 | 云台状态错误 |
| 4 | CAN2 / IMU 通信超时或 IMU 无效 |

## 3. 主控板 <-> 末端副板

### 3.1 串口参数

| 项目 | 参数 |
|---|---|
| 接口 | UART5 / RS485 |
| 波特率 | 115200 |
| 数据位 | 8 |
| 停止位 | 1 |
| 校验 | 无 |
| 最大 payload | 32 bytes |

### 3.2 帧格式

```text
+--------+---------+--------+-------------+----------+----------+----------+
| 0xA6   | node_id | cmd_id | payload_len | payload  | crc_low  | crc_high |
+--------+---------+--------+-------------+----------+----------+----------+
  1 byte   1 byte    1 byte    1 byte       N bytes    1 byte     1 byte
```

字段说明：

| 字段 | 说明 |
|---|---|
| `0xA6` | 固定帧头 |
| `node_id` | 当前固定为 `0x01` |
| `cmd_id` | 命令或反馈 ID |
| `payload_len` | payload 长度，范围 `0~32` |
| `payload` | 数据区 |
| `crc_low/crc_high` | CRC16-CCITT，小端 |

CRC 规则：

| 项目 | 参数 |
|---|---|
| 算法 | CRC16-CCITT |
| 初值 | `0xFFFF` |
| 多项式 | `0x1021` |
| 覆盖范围 | `node_id + cmd_id + payload_len + payload` |
| 是否包含帧头 | 不包含 |

### 3.3 主控板 -> 副板命令

| ID | 名称 | Payload |
|---:|---|---|
| `0x01` | `HEARTBEAT` | 空 |
| `0x02` | `ESTOP` | 空 |
| `0x03` | `STOP` | 空 |
| `0x04` | `SET_MODE` | `u8 mode` |
| `0x20` | `SERVO123_SPEED` | `s16 speed0`, `s16 speed1`, `s16 speed2` |
| `0x21` | `SERVO123_POSITION` | `s16 pos0`, `s16 pos1`, `s16 pos2`, `u16 run_time`, `u16 speed` |
| `0x30` | `AUTO_START` | `u16 forward_ms`, `u16 reverse_ms`, `s16 speed` |
| `0x31` | `AUTO_STOP` | 空 |
| `0x40` | `PUSHROD` | 已定义，当前主板发送侧尚未封装 |

副板模式：

| 值 | 含义 |
|---:|---|
| `0` | 遥控速度模式 |
| `1` | 上位机位置模式 |
| `2` | 自动任务模式 |
| `3` | 急停模式 |

### 3.4 副板 -> 主控板反馈

| ID | 名称 | Payload |
|---:|---|---|
| `0x80` | `ACK` | `u8 state`, `u8 status`, `u8 ack_cmd_id` |
| `0x81` | `STATE` | `u8 state`, `u8 error` |
| `0x82` | `SERVO` | 已定义，当前主板未解析 |
| `0x83` | `ERROR` | `u8 error` |

主板当前会保存最近一次 ACK 对应的命令 ID，可通过 `SubBoard_LinkGetLastAckCmd()` 获取。

副板状态：

| 值 | 含义 |
|---:|---|
| `0` | 未知 |
| `1` | 空闲 |
| `2` | 遥控模式 |
| `3` | 上位机模式 |
| `4` | 自动任务运行中 |
| `5` | 完成 |
| `6` | 错误 |
| `7` | 急停 |

副板错误码：

| 值 | 含义 |
|---:|---|
| `0` | 无错误 |
| `1` | CRC 错误 |
| `2` | 长度错误 |
| `3` | 超时 |
| `4` | 传感器错误 |
| `5` | 推杆错误 |
| `6` | 舵机错误 |

## 4. 上位机开发建议

1. 每条上位机命令必须按帧格式封装 CRC。下位机只处理 CRC 正确的帧。
2. 上位机进入控制模式后，应以小于 500 ms 的周期发送命令或心跳。
3. 云台位置控制建议使用 `0x32 EXEC_PTZ_ANGLE`，由下位机基于 IMU 做闭环。
4. 钢带长度控制建议使用 `0x12 YUSHU_LENGTH`，由下位机基于编码器做闭环。
5. 停止运动时，上位机应主动发送速度 0 或切回遥控源；下位机也有超时保护，但不应依赖超时作为正常停车手段。
6. 上位机解析反馈时，应按 `cmd_id` 区分 `ARM_STATE`、`ACTUATOR_ECHO` 和 `DIAG`，不要假设反馈帧固定交替到达。

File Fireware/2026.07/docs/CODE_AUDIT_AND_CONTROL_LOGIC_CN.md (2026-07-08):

# TapBot 主控/副控固件审查与控制逻辑

审查日期：2026-07-04  
范围：`TapBot_RemoteControl_Mode`（STM32F107VC 主控）与 `EndEffector_SubBoard`（STM32F103C8 副控）当前工作区版本。

## 1. 结论摘要

两套工程都能由 ARMCC 5.06 update 6 完整生成固件，但“编译通过”不代表当前版本适合直接上机。主控全量重编译为 **0 error / 5 warnings**，副控为 **0 error / 0 warnings**。静态审查发现多项控制安全和功能风险，其中副控舵机与主副板通信共用 USART1、通信失联停机、反馈新鲜度以及自动任务停止语义应在联机测试前优先处理。

## 2. Keil 构建结果

| 工程 | 芯片 | 结果 | 固件占用 |
| --- | --- | --- | --- |
| `RemoteControl_Mode` | STM32F107VC | 0 errors, 5 warnings | Code 35,228 B；RO 880 B；RW 716 B；ZI 4,476 B |
| `EndEffector_SubBoard` | STM32F103C8 | 0 errors, 0 warnings | Code 4,844 B；RO 272 B；RW 40 B；ZI 1,200 B |

主控告警均为未使用符号：`Comm/usart.c` 3 个局部变量、`Comm/can1.c` 的 `io_temp`、`Actuators/yushu_motor_data.c` 的 `Yushu_ScaleFloat()`。

## 3. 问题清单

### P0：上机前应解决

1. **副控的主板 RS485 链路与飞特舵机发送共用 USART1/PA9，且舵机发送不拉高 RS485 DE。**  `BSP/usart.c:10-29` 仅初始化 USART1（PA9/PA10），`Actuators/feetech_servo.c:36-39` 又通过同一个 `SubUart_SendByte()` 发舵机帧，而 DE 只在 `Comm/rs485_link.c:168-177` 的主副板协议发送时控制。按当前代码，舵机帧很可能无法送到舵机，或与主副板链路发生总线冲突。必须结合原理图确认舵机物理接口；通常应为舵机配置独立 UART/半双工收发器。

2. **副控没有主控心跳看门狗。** 主控每约 0.5 s 发送心跳，但副控只响应状态，没有记录最后接收时间或在超时后执行 `StopAll + Pushrod_Stop`。主副板线缆断开时，速度模式舵机、ID3 自动流程或推杆可能继续保持最后状态。

3. **遥控失联停机约需 50.1 s。** `Protocols/rmt_data.c:255` 每次有效帧把 `CntRxRmt` 设为 1000；该计数在约 50.1 ms 的 TIM4 中断中递减（`BSP/timer.c:183-186`），因此失联检测不是 1 s，而约为 50.1 s。对运动机构而言过长。

4. **编码器和 IMU 的 `valid` 只会置 1，不会在 CAN 超时后清零。** CAN 超时仅设置 `CAN1_OutCommunFlg`/`CAN2_OutCommunFlg`；长度 PID 和云台角度闭环仍直接依赖缓存中的 `valid`。断线后系统可能继续使用旧位置/姿态执行闭环。应引入数据时间戳/年龄，并在超时入口使反馈失效且停机。

5. **自动任务停止/报错不会撤销宇树长度闭环目标。** `ArmAutoTask_Stop()` 与 `ArmAutoTask_SetError()` 只停止云台和副控自动任务；此前写入 `UpperCmd` 的 `yushu_length_ctrl_enable` 和目标长度仍可被 30 ms 控制循环持续执行。自动停止应发布完整零速/取消位置环命令。

### P1：高优先级功能与安全问题

6. **上位机心跳会持续“续命”旧运动指令。** `UPPER_CMD_HEARTBEAT` 重置与命令共用的 `UpperTimeoutTicks`；只要心跳存在，旧 `UpperCmd` 可无限保持。链路在线但控制节点卡死时，旧速度仍有效。应分离 link watchdog 与 command watchdog，并要求运动命令周期刷新。

7. **上位机的舵机速度统一命令链路不完整。** `UPPER_CMD_STEER_SYNC` 只更新 `UpperCmd`，但 100 ms 的 `Steer_ControlProc()` 仅在遥控模式执行；`UPPER_CMD_EXEC_STEER_SPEED` 又只写 ID3，随后调用的 `SendSteer_Rotate_SpeedRun()` 是空函数。因此 0x20/0x21 不能按接口语义驱动 ID0-ID2。

8. **上位机失联时自动流程未被显式中止。** 控制源回退只停止云台，没有调用 `ArmAutoTask_Stop()`；若副控自动流程已经启动，它会继续运行到完成或自身超时。

9. **副控 E-stop 不锁存。** `EndEffectorTask_EStop()` 进入 ESTOP，但随后 `AUTO_STOP/STOP` 会调用 `EndEffectorTask_StopAuto()` 并直接回到 IDLE。若急停要求人工复位，应增加独立、明确的 reset 命令，普通 stop/mode 命令不能解除急停。

10. **推杆回缩以 5 s 定时结束作为“完成”，没有到位反馈。** `END_AUTO_PUSHROD_TIMEOUT_MS` 到时后直接进入 DONE，而不是报超时；这无法区分正常到位、堵转和线缆故障。建议增加伸出/缩回限位或电流判据。

11. **CAN1 过滤器在字段赋值前调用初始化函数。** `Comm/can1.c:129-138` 首次 `CAN_FilterInit(&CAN_FilterInitStructure)` 使用未初始化的栈变量，随后才赋值并再次初始化。第一次调用应删除。

### P2：可靠性和维护问题

12. **调度周期存在约 10% 偏差。** 72 MHz 定时器时钟、PSC=7199、ARR=10 时，中断周期为 `(7199+1)×(10+1)/72 MHz = 1.1 ms`；累计 10 次后所谓“10 ms”实际为 11 ms。TIM4 的 ARR=500 对应 50.1 ms。应使用 ARR=9/499，或统一基于测得时基配置 PID 与超时。

13. **`flag10ms` 是布尔标志，主循环阻塞时会丢调度拍。** 改为递增 tick 计数或基于单调时钟追赶任务更稳健。

14. **TIM3/TIM4 同时开启 Update 与 Trigger 中断，但 ISR 只处理/清除 Update。** 若产生 trigger 事件，可能留下未清中断源。当前不需要 Trigger 时应只开 Update。

15. **副控错误码不会在新任务或正常 stop 时清零。** 传感器超时后的 `EndError=4` 会继续随后续正常状态上报。

16. **环形缓冲区溢出被静默忽略。** 主副控 ISR 都忽略 `ring_buf_put()` 的返回值，无法诊断丢帧；应累计 overflow 计数并上报。

17. **主控初始化阶段会向 USART2 上位机二进制链路发送文本/原始字节。** `Encoder_Set_Resp_Fun()` 的 `"transmit Ok"` 和 `Encoder_Read_Pos_Dirc_Fun()` 的原始 CAN 缓冲未受 `APP_USART2_TEXT_DEBUG` 保护，可能干扰上位机帧同步。

18. **状态定义与实现有漂移。** 副控定义了 `WAIT_OBJECT_CLEAR`，实现未进入该状态；注释、README 与当前执行路径也有若干差异。建议由状态表生成文档或至少建立单元测试保持同步。

## 4. 当前控制逻辑

### 4.1 主控启动与周期任务

1. 初始化 72 MHz 系统、LED/NVIC、USART1~5、CAN1/2、开关量、控制分配器、TIM3/4、舵机模式、云台、编码器和 IMU。
2. 主循环持续解析 USART2 上位机帧、USART3 遥控帧和 UART5 副控反馈。
3. 名义 10 ms：控制源仲裁、机械臂自动任务、副控在线计时；每 500 ms 发送副控心跳。
4. 名义 30 ms：宇树 M8010 速度/长度 PID、离合和限位逻辑。
5. 名义 50 ms：上位机状态/执行器/诊断反馈；上位机模式下执行云台速度或角度闭环。
6. 名义 100 ms：仅遥控模式下执行 ID0-ID2 舵机速度命令，并用 D 键边沿触发/停止副控自动流程。

### 4.2 控制源仲裁

- 遥控器 H 通道选择 RMT 或 UP 模式。
- 只有同时满足“请求 UP、已有有效 UpperCmd、上位机在 500 ms 窗口内活跃”时，主控采用上位机命令。
- 其余情况回退到遥控；若遥控被判定失联，则发布零运动和离合关闭。
- 从 UP 回退 RMT 时仅显式停止云台，未完整停止自动任务和所有执行器。

### 4.3 主控自动流程

`ARM_AUTO_START (0x40)` 携带 flags、云台角度、宇树目标长度、ID0-ID2 位置、副控正反转时长/速度和回缩长度：

`MOVE_TO_TARGET → WAIT_ARM → END_AUTO（可选）→ RETRACT（可选）→ DONE`

- `MOVE_TO_TARGET`：一次性发布云台角度、宇树长度目标和 ID0-ID2 位置。
- `WAIT_ARM`：检查编码器有效性、最小稳定时间和目标长度容差；12 s 超时。
- `END_AUTO`：要求副控在线，发送自动启动，并等待副控 DONE/IDLE；20 s 超时。
- `RETRACT`：停止云台/副控，ID0-ID2 回零，宇树回到回缩长度；12 s 超时。
- 任意错误进入 ERROR；当前 ERROR/ABORT 不会自动回到 IDLE。

### 4.4 副控手动与自动流程

- REMOTE_SPEED：ID0-ID2 接收速度命令。
- UPPER_POSITION：ID0-ID2 接收位置、运行时间和速度命令。
- AUTO：`WAIT_OBJECT → PUSHROD_EXTEND → PRESS_HOLD → SERVO_FORWARD → SERVO_REVERSE → PUSHROD_RETRACT → DONE → IDLE`。
- 光电传感器在 5 s 内未检测物体则 ERROR；ID3 正转指定时间，再反转直到物体离开或反转时间到；推杆固定回缩 5 s 后视为完成。

### 4.5 通信协议

- 上位机：`A5 | cmd | len | payload | CRC16-L | CRC16-H`，CRC 覆盖 cmd/len/payload。
- 主副板：`A6 | node=01 | cmd | len | payload | CRC16-L | CRC16-H`，CRC 覆盖 node/cmd/len/payload。
- 主控每约 0.5 s 发心跳；副控用 STATE 应答。命令 0x01~0x7F 为主到副，反馈 0x80~0xFF 为副到主。

## 5. 建议整改顺序

1. 先确认副控原理图并拆分/修正飞特舵机 UART 与 RS485 DE 控制。
2. 建立统一安全停机函数，覆盖 M8010、ID0-ID3、云台、推杆和离合；由遥控、上位机、主副板、CAN 反馈 watchdog 共同调用。
3. 将通信在线与运动命令新鲜度分开计时；超时默认进入 stop，而不是无条件切换到另一个控制源。
4. 为 encoder/IMU/subboard feedback 增加时间戳，并让闭环控制只接受未过期数据。
5. 修复上位机舵机速度链路、定时器 ARR 和 E-stop 复位语义。
6. 建立台架故障注入测试：拔遥控、拔上位机、断 UART5、断 CAN1/2、传感器常高/常低、推杆堵转。

## 6. 审查边界

本次为源代码静态审查、工程配置检查和 Keil 全量构建；未包含原理图、示波器/逻辑分析仪采样、执行器台架或硬件在环验证。与引脚、收发器和传感器极性有关的结论需在硬件资料上最终确认。

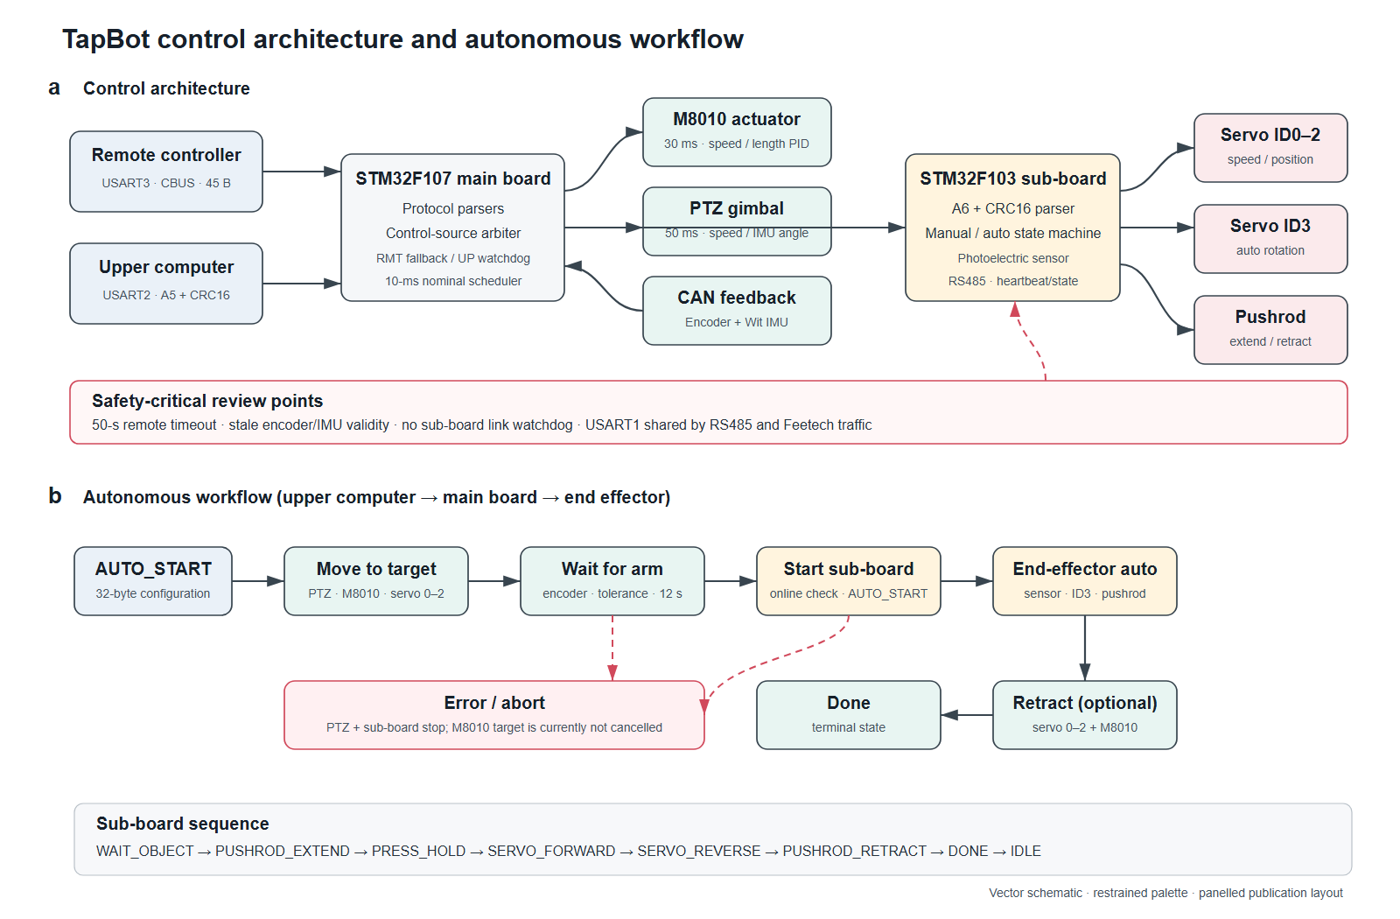
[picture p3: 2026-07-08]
Fireware/2026.07/docs/tapbot_control_logic_nature.png

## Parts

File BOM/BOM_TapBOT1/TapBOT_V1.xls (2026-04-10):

BOM(Bill of Materials)
No. | Comment | Description | Designator | Footprint

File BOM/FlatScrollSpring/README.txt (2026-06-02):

================================================================================
                    平面涡旋卷簧（发条弹簧）设计说明
                                  用于卷线器
================================================================================

【目的】
为卷线器（自动回收线缆）设计一个平面涡卷弹簧，使其能在规定的安装空间内，
提供所需的回收力（扭矩），并满足工作圈数和疲劳寿命要求。

【核心公式】
扭矩 M 与卷紧角度 φ 呈线性关系：

    M = K * φ

其中扭转刚度 K 为：
    K = (E * b * h^3) / (12 * L)
里面：
    M   – 扭矩，单位 N·mm 或 N·m（你卷线器需要多大力，就靠它）
    φ   – 拧紧的角度，单位 弧度（1圈 = 2π ≈ 6.28 弧度）
    E   – 材料弹性模量，弹簧钢你就用 206000 N/mm²，不用纠结
    b   – 弹簧片子的宽度（mm）
    h   – 弹簧片子的厚度（mm）—— 这个最要命，h 变一点，扭矩变化巨大（三次方）
    L   – 弹簧展开后的总长度（mm）

另外，还得看一眼弹簧会不会被拧断：

    σ_max = 6 * M_start / (b * h^2)  ≤ 许用应力 [σ]

（M_start 是线完全拉出时的扭矩，这时候应力最大）

【空间限制（弹簧盒内可容纳的最大长度）】
弹簧要卷在盒子里，不能超过盒子能装的最大长度：

    L_max ≈ π * (D_o^2 - D_i^2) / (4 * h)
其中：
    D_o – 弹簧盒内径
    D_i – 心轴外径

【设计步骤（快速流程）】
1. 确定输入参数
   – 终点扭矩 M_end（线缆完全收回时需要的扭矩）
   – 起点扭矩 M_start（线缆完全拉出时需要的扭矩）
   – 工作圈数 Δn（从收回到拉出的卷盘旋转圈数）
   – 安装空间：心轴外径 D_i，弹簧盒内径 D_o，可用宽度 B
   – 材料许用应力 [σ] 和安全系数

2. 计算所需刚度 K
   K = (M_start – M_end) / (2π * Δn)

3. 初选截面尺寸 b, h
   b ≤ B – 1~2 mm (留间隙)
   h 建议从 0.2~0.5 mm 开始尝试

4. 计算所需弹簧长度 L
   L = (E * b * h^3) / (12 * K)

5. 校核空间容纳能力
   若 L > π*(D_o^2 – D_i^2)/(4*h) 
   → 弹簧太长，需减小 h 或增大盒子

6. 校核最大应力
   计算 σ_max = 6*M_start/(b*h^2)
   若 σ_max > [σ] → 需增大 b 或 h
（优先增大 b，因为 b 不影响空间限制，只影响应力和刚度）
（但增大 h 会同时增加 L，可能恶化空间问题）

7. 确定预紧圈数与总圈数
   预紧圈数 n0 = M_end / (2π*K)
   总圈数 n_total ≈ (D_o – D_i) / (2*h)
   需满足 n0 + Δn ≤ n_total (防止弹簧锁死)

8. 迭代调整以上参数，直至所有约束满足。

================================================================================
版本：1.0
================================================================================

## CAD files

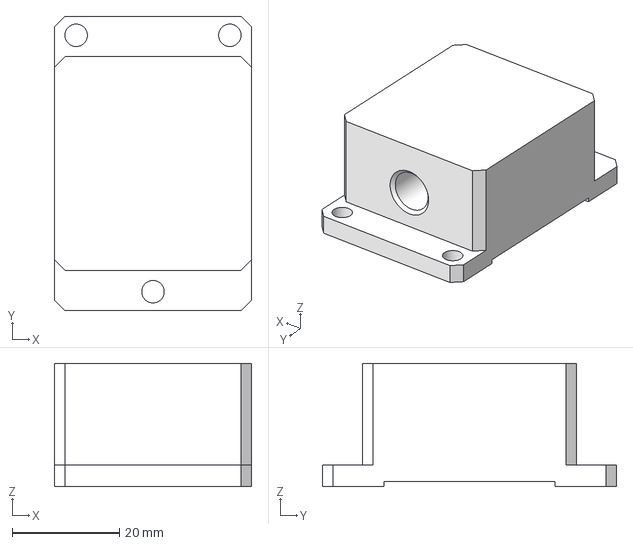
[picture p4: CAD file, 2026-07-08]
TapSpingROT_STL/IMU/HWT901-CAN.stp
36.8 x 55.0 x 23.0 mm

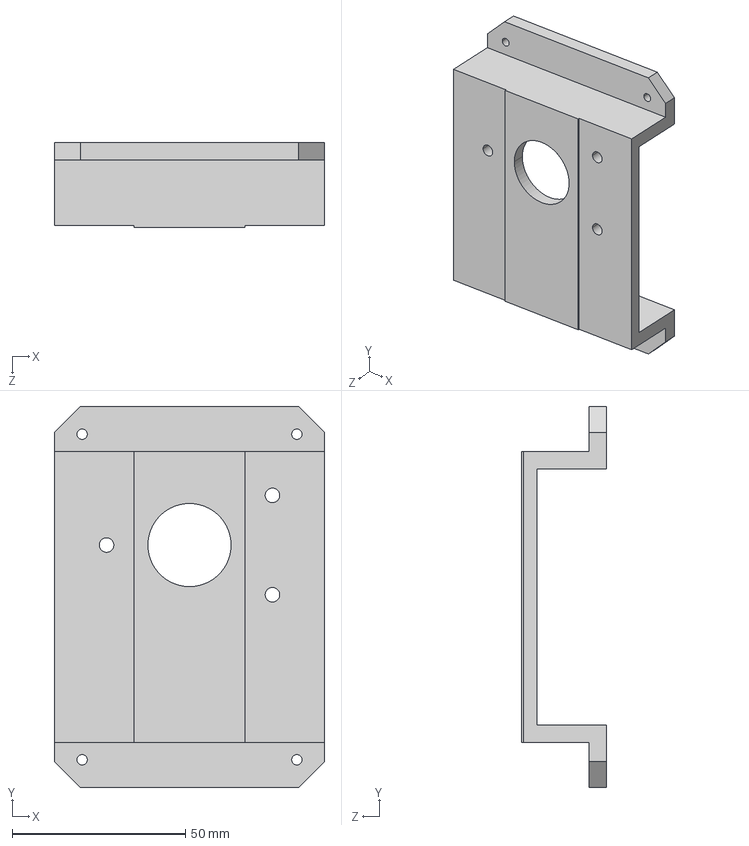
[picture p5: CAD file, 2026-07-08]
TapSpingROT_STL/IMU/IMU_01_bracket.STEP
78.0 x 110.0 x 24.5 mm

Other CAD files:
TapSpingROT_Model/IMU/HWT901-CAN.SLDPRT
TapSpingROT_Model/IMU/IMU_01_bracket.SLDPRT

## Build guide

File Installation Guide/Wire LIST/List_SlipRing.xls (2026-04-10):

这个文件是解释导电滑环的接线即安装顺序；
This document explains the wiring and installation procedure for conductive slip rings;
Note: Incorrect wiring may prevent the end joint from moving; alternatively, you can connect the end platform directly using a wire.
序号/NO. | 种类/Category | 次序号/NO. | 颜色/color | 安装/Connect | 序号/NO. | 颜色/color | 组别/group
1 | 电线1/Electric wire1 | a |  | → | 1 | 黑色 | 3
2 |  |  | 红/red
3
4 | 电线2/Electric wire2 | b | 紫/purple | → | 2 |  | 10
5 |  |  | 黑/black
6
7 | 电线3/Electric wire3 | c | 红/red | → | 3 |  | 4
8 |  |  | 黄/yellow
9 |  |  | 绿/green
10 | 电线4/Electric wire4 | d | 蓝/blue | → | 4 |  | 9
11 |  |  | 棕/brown
12
13 | 信号线/Signal line | e | 蓝/blue | → | 5 |  | 5
14 | 信号线/Signal line | f | 黑/black | → | 6 |  | 2
15 | 信号线/Signal line | g | 紫/purple | → | 7 |  | 1
16 | 信号线/Signal line | h | 红/red | → | 8 |  | 6
17 | 485 | i | 绿/green | → | 9 |  | 8
18 | 485 | j | 棕/brown | → | 10 |  | 7

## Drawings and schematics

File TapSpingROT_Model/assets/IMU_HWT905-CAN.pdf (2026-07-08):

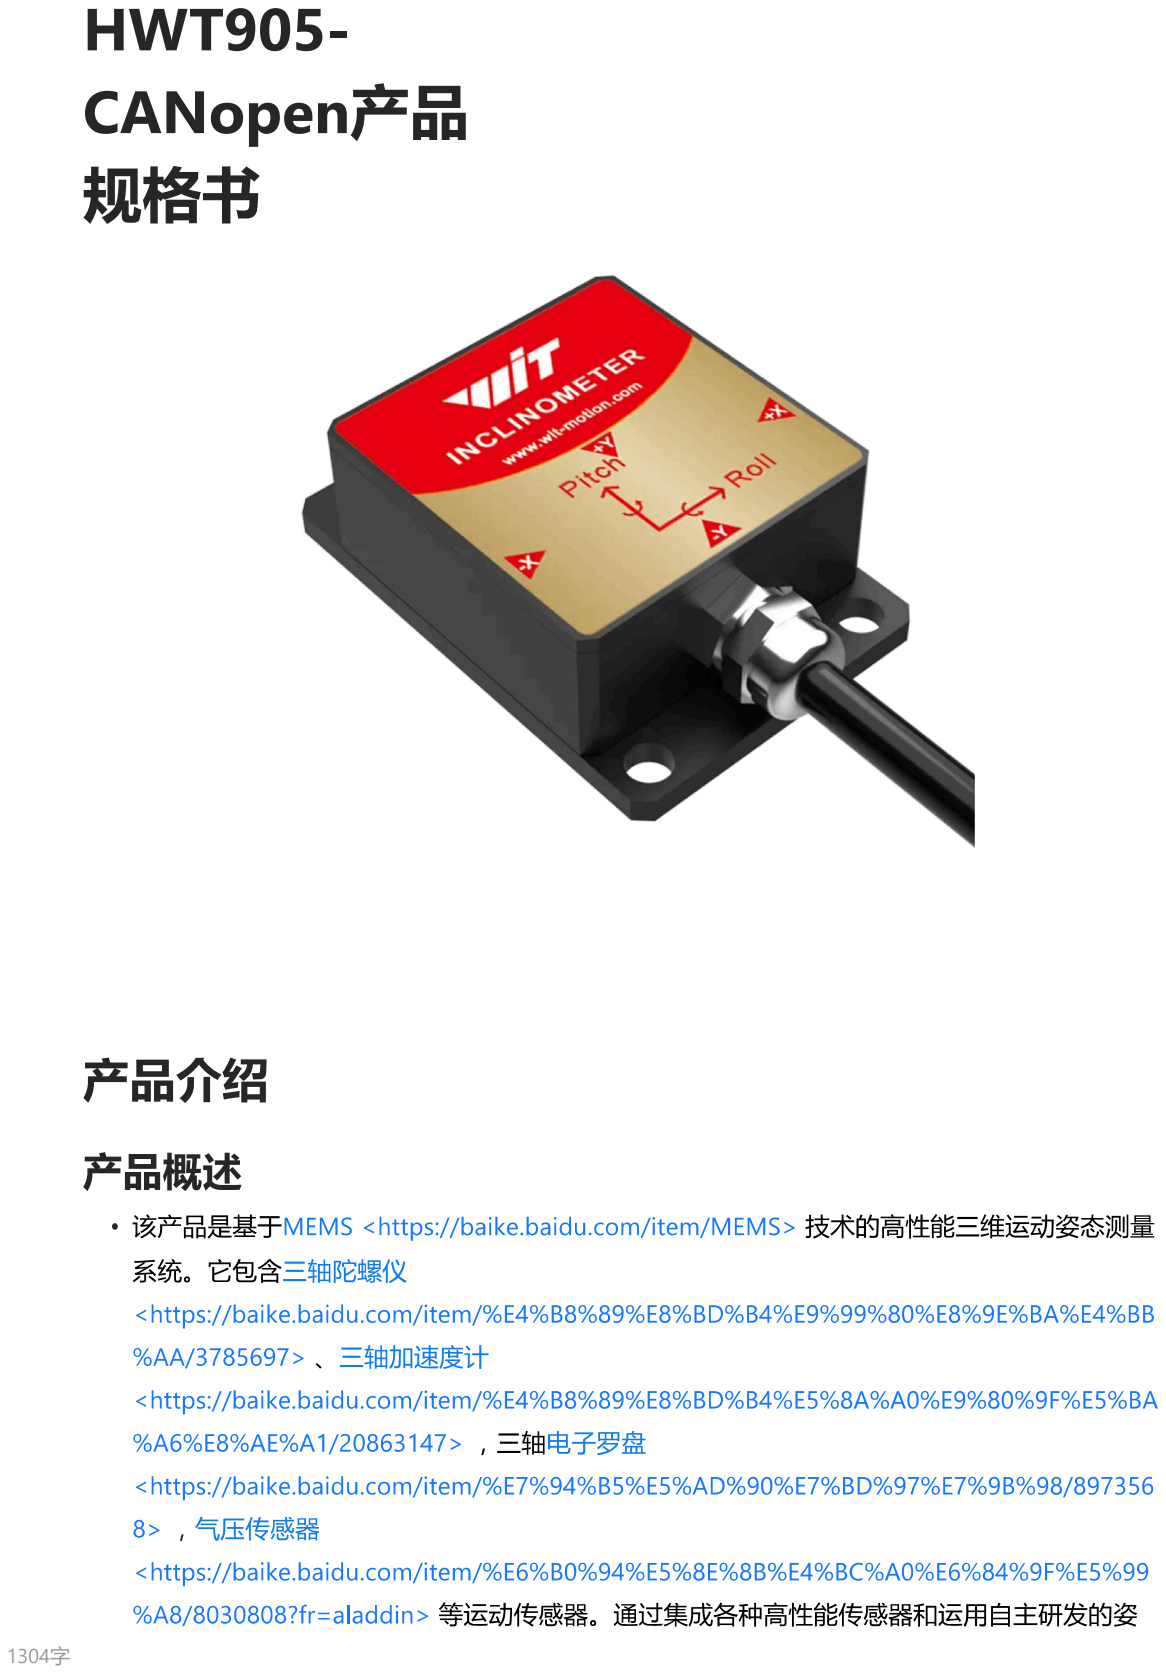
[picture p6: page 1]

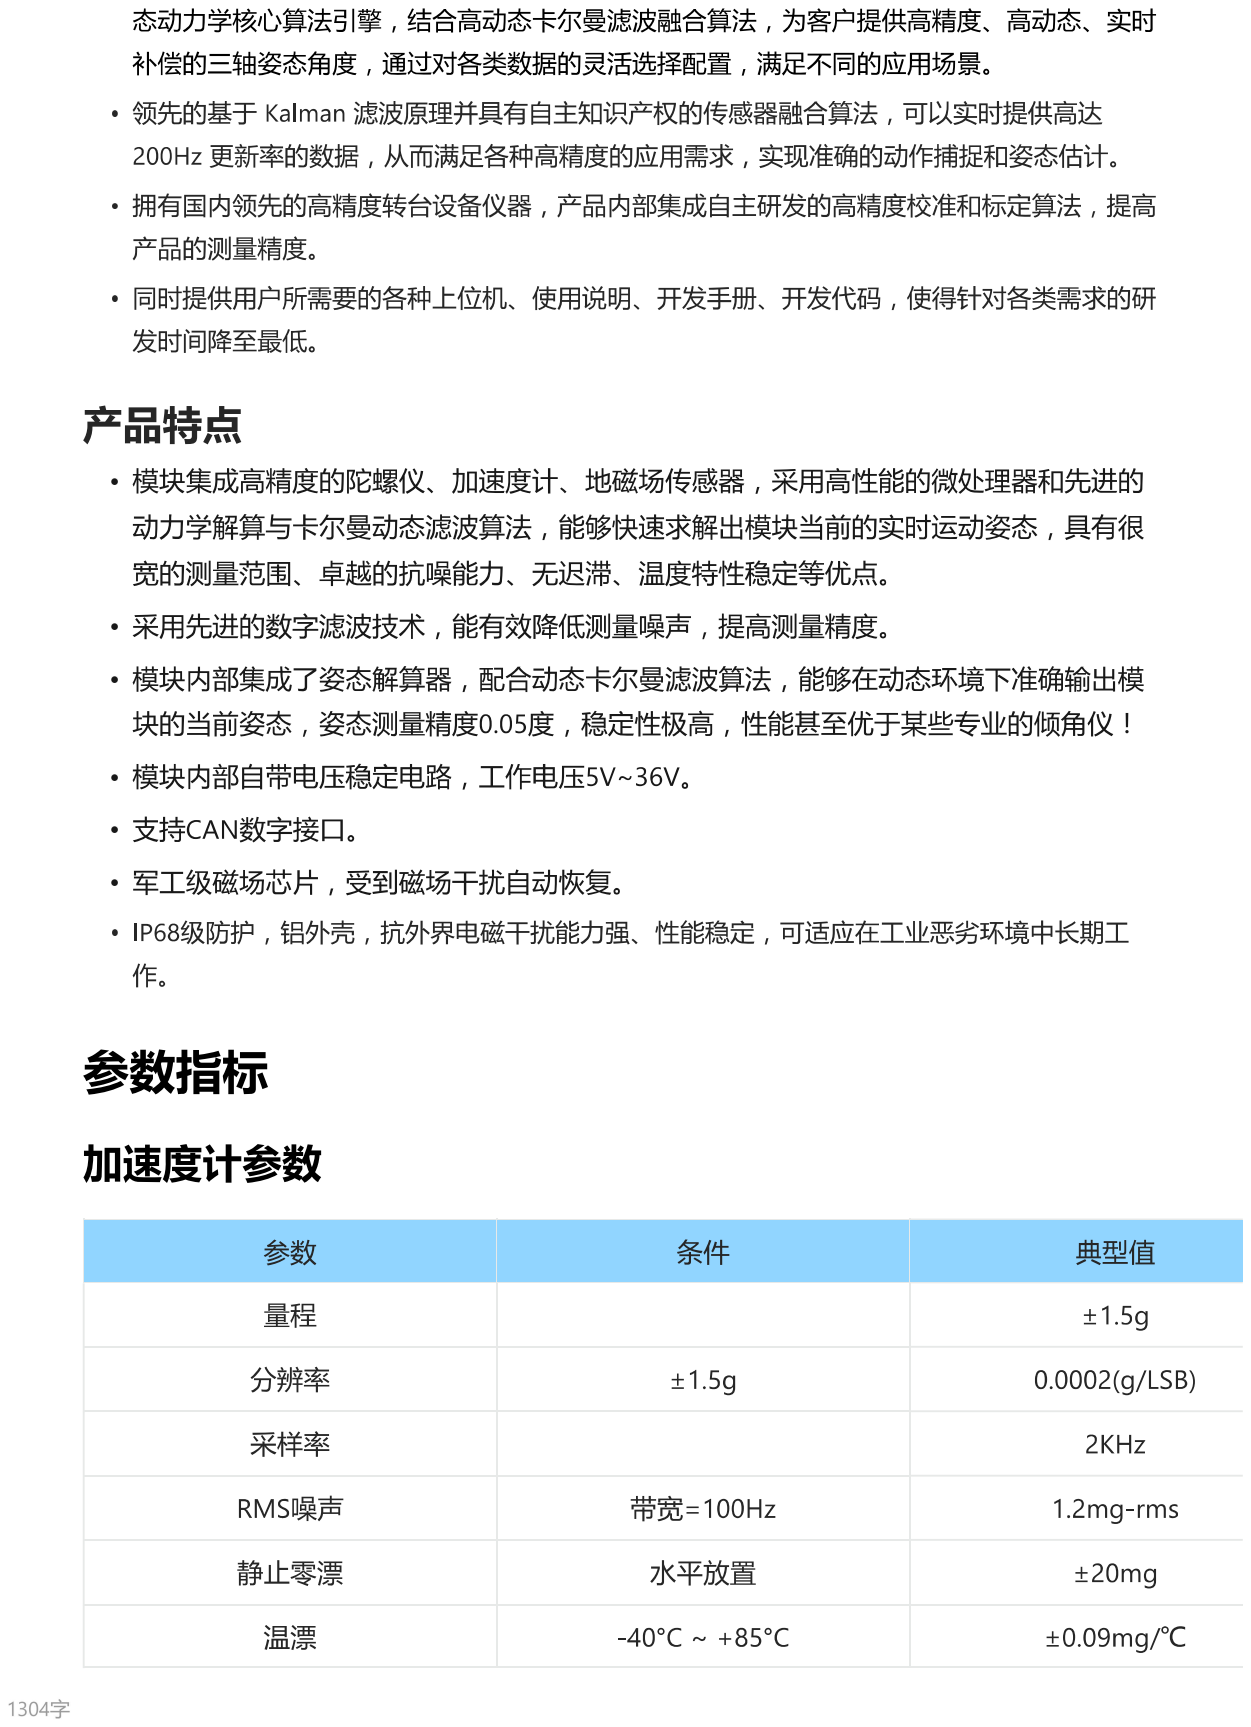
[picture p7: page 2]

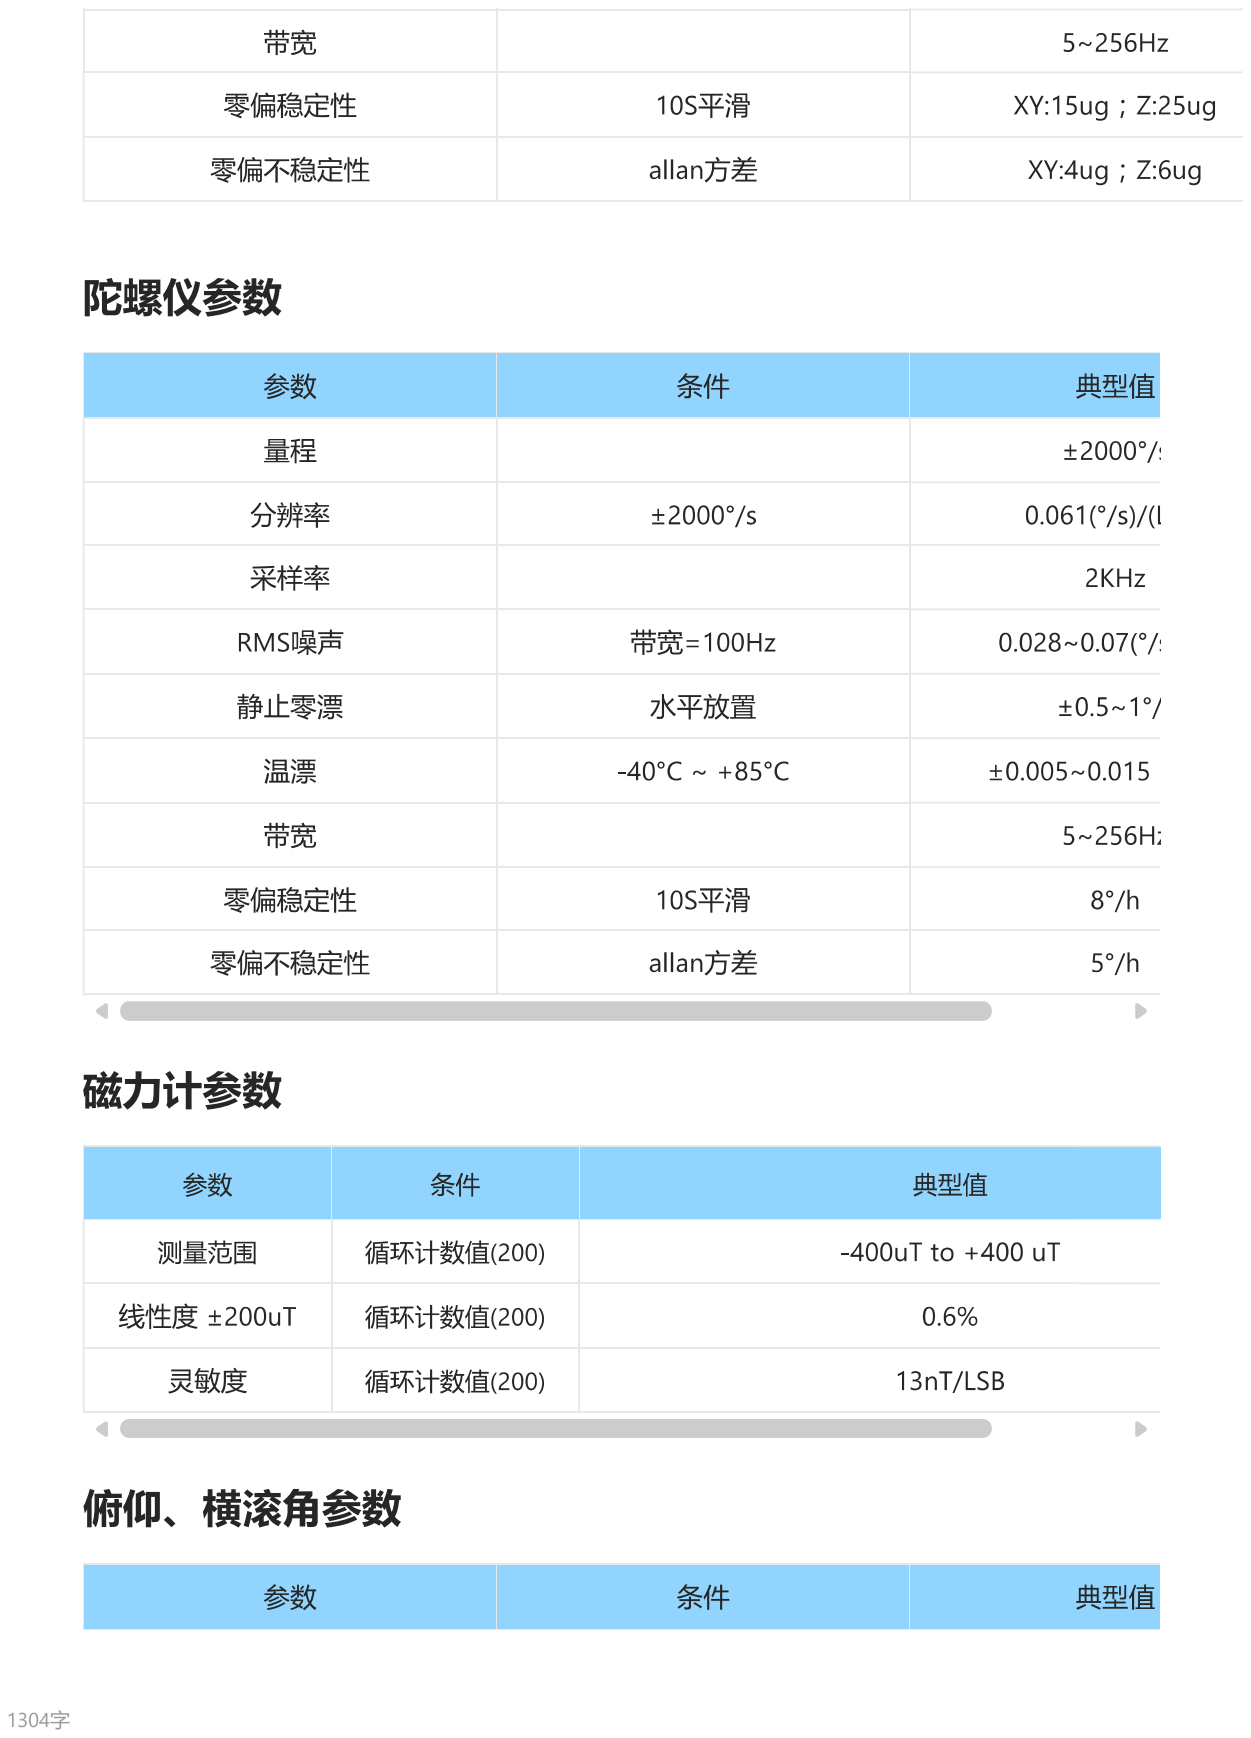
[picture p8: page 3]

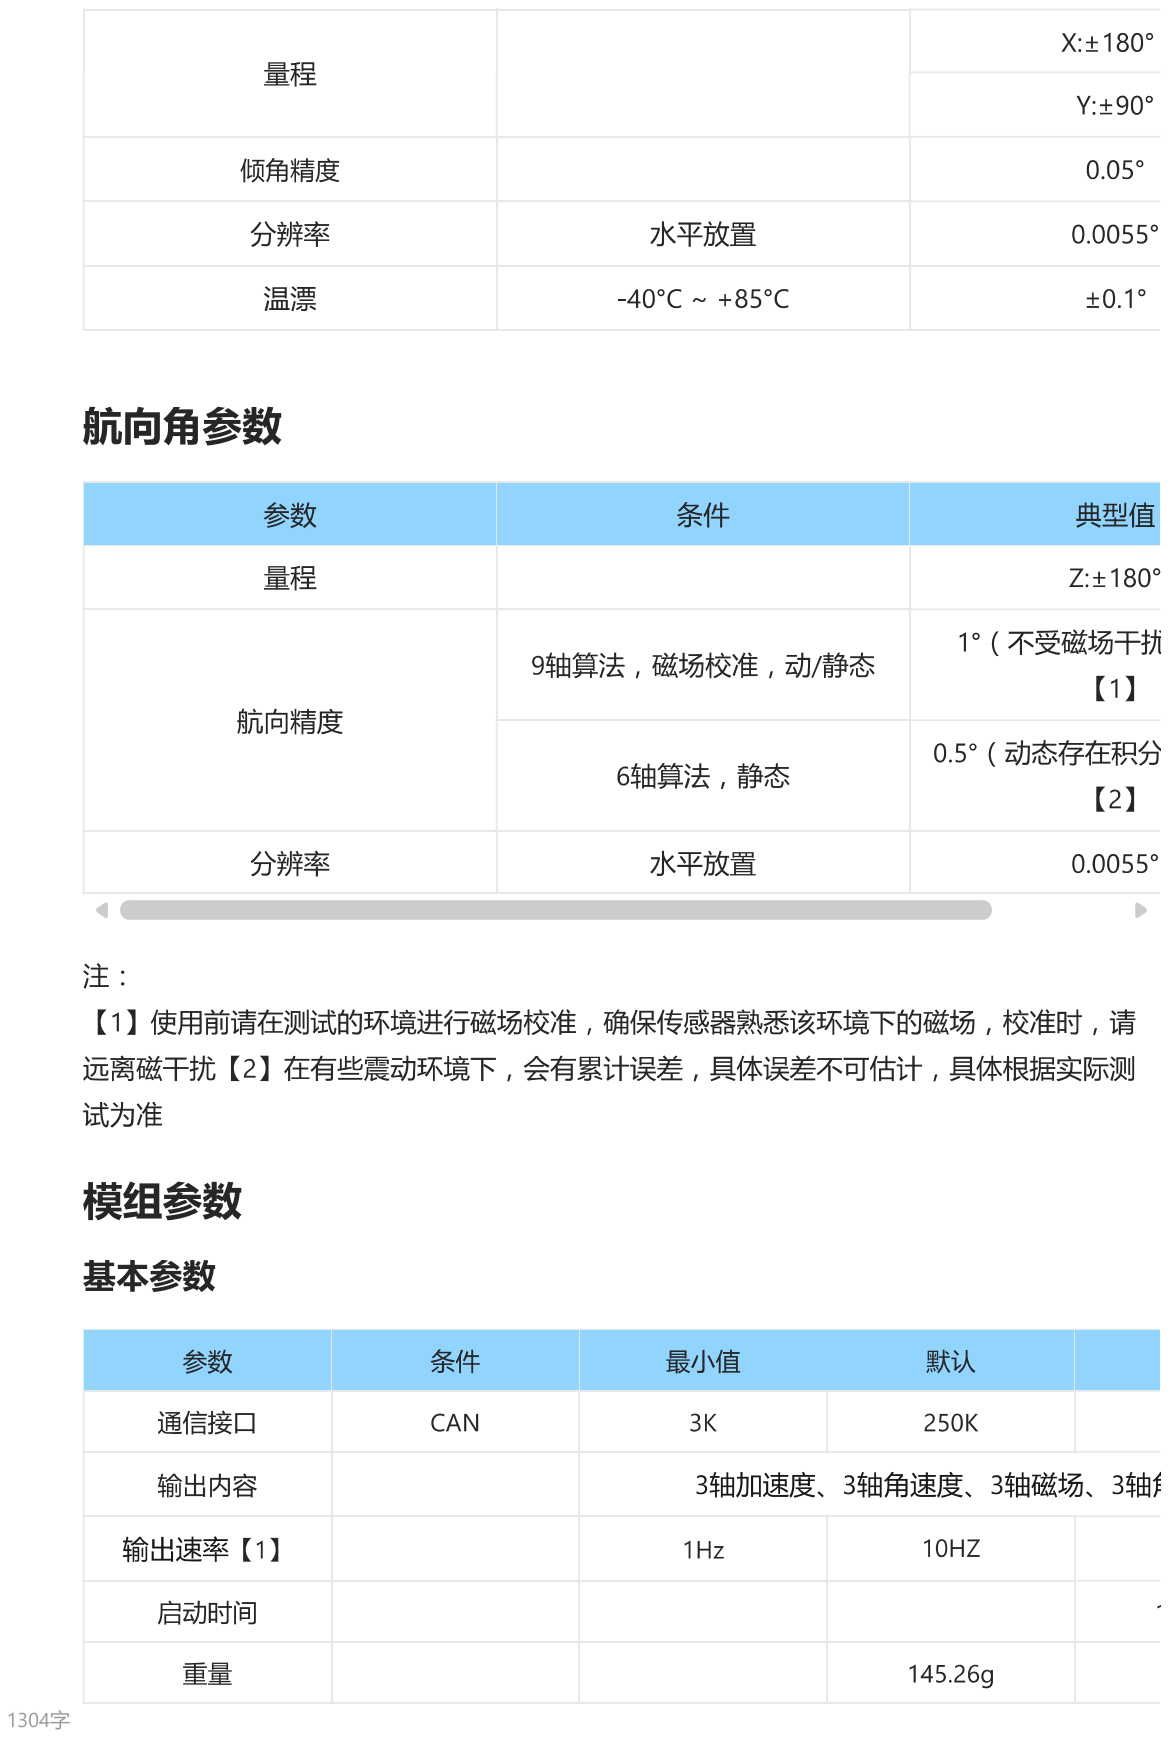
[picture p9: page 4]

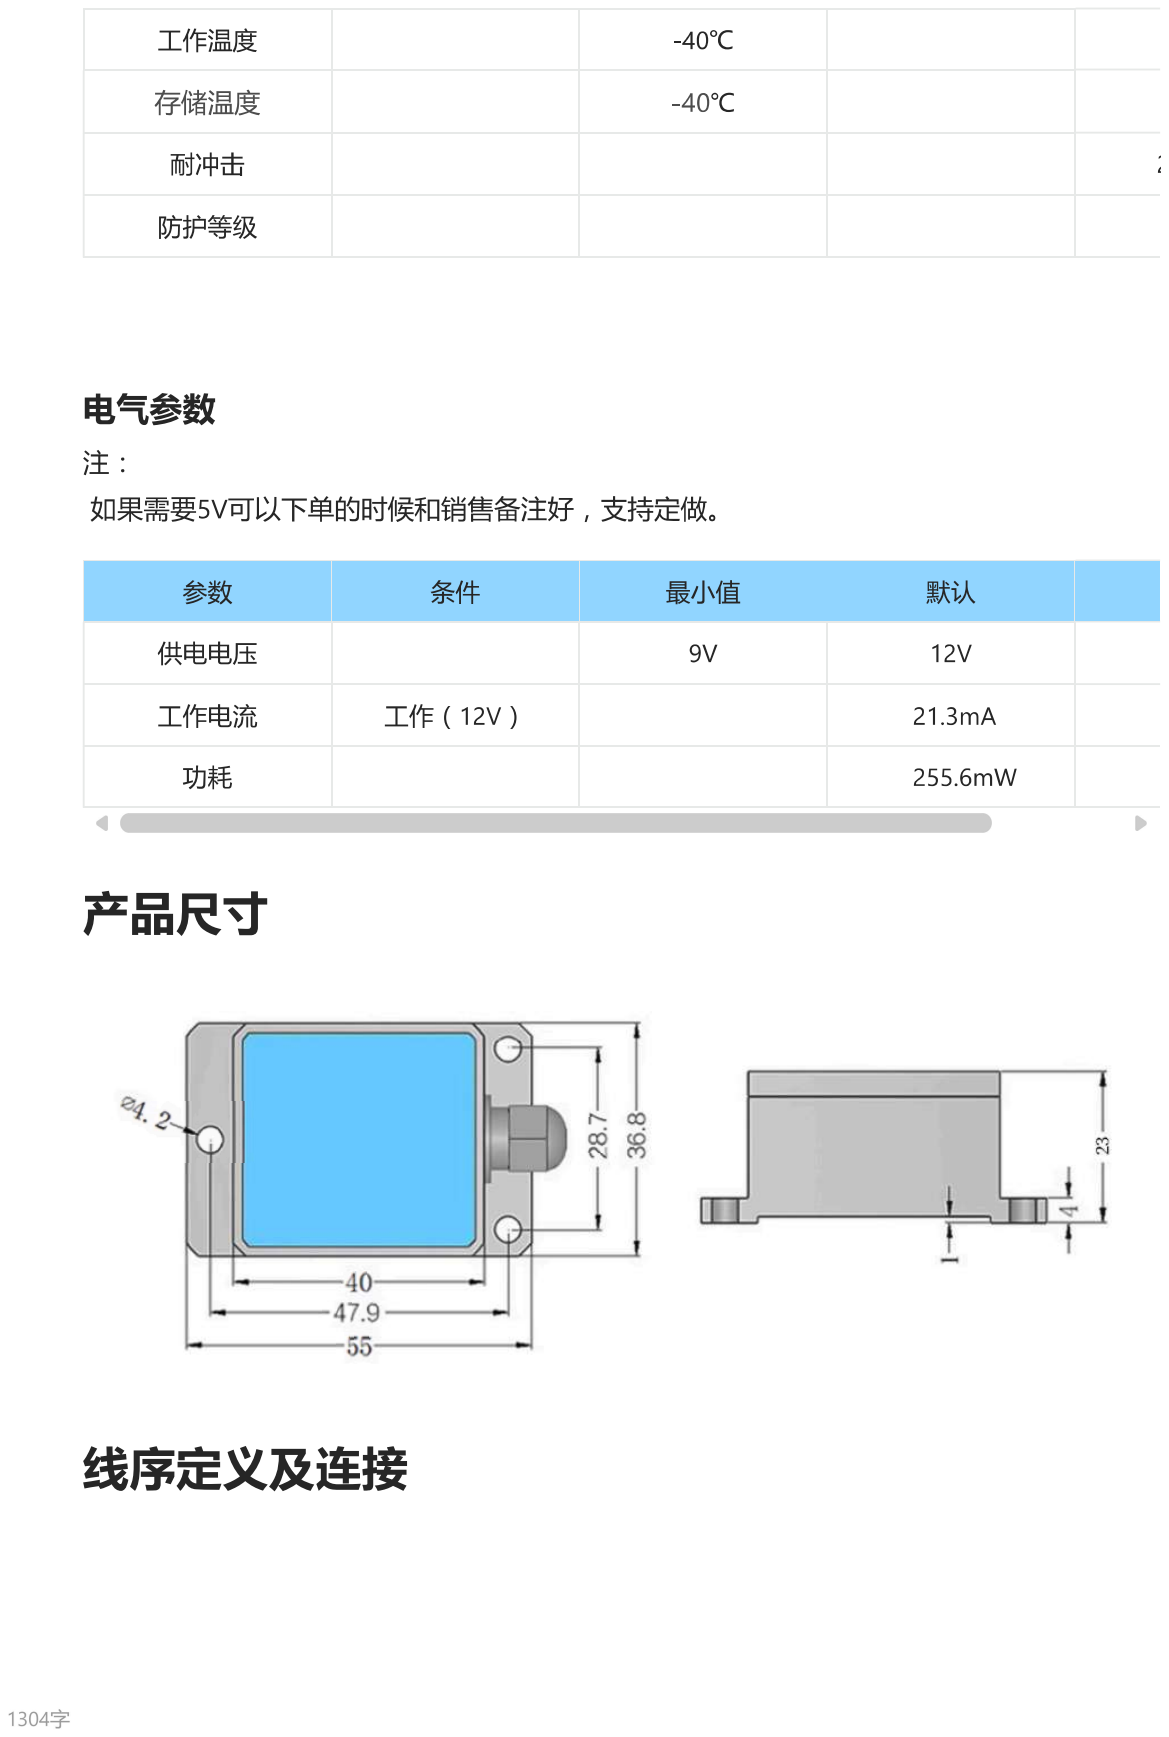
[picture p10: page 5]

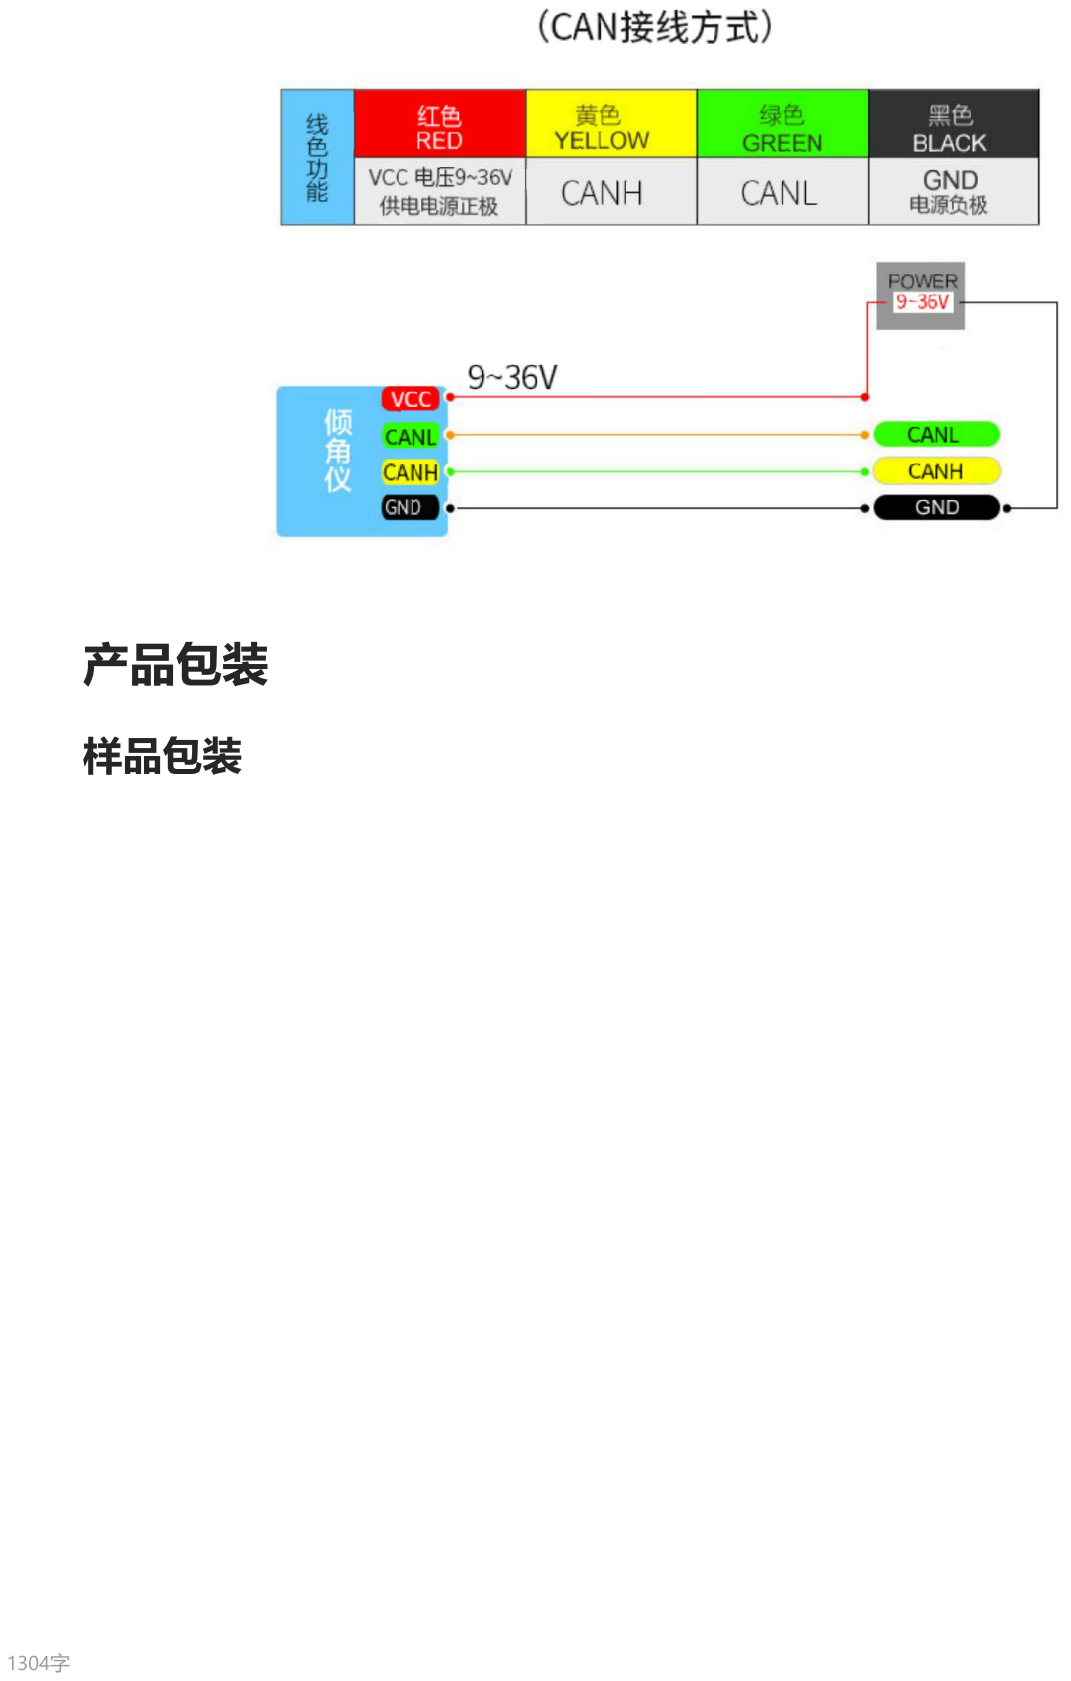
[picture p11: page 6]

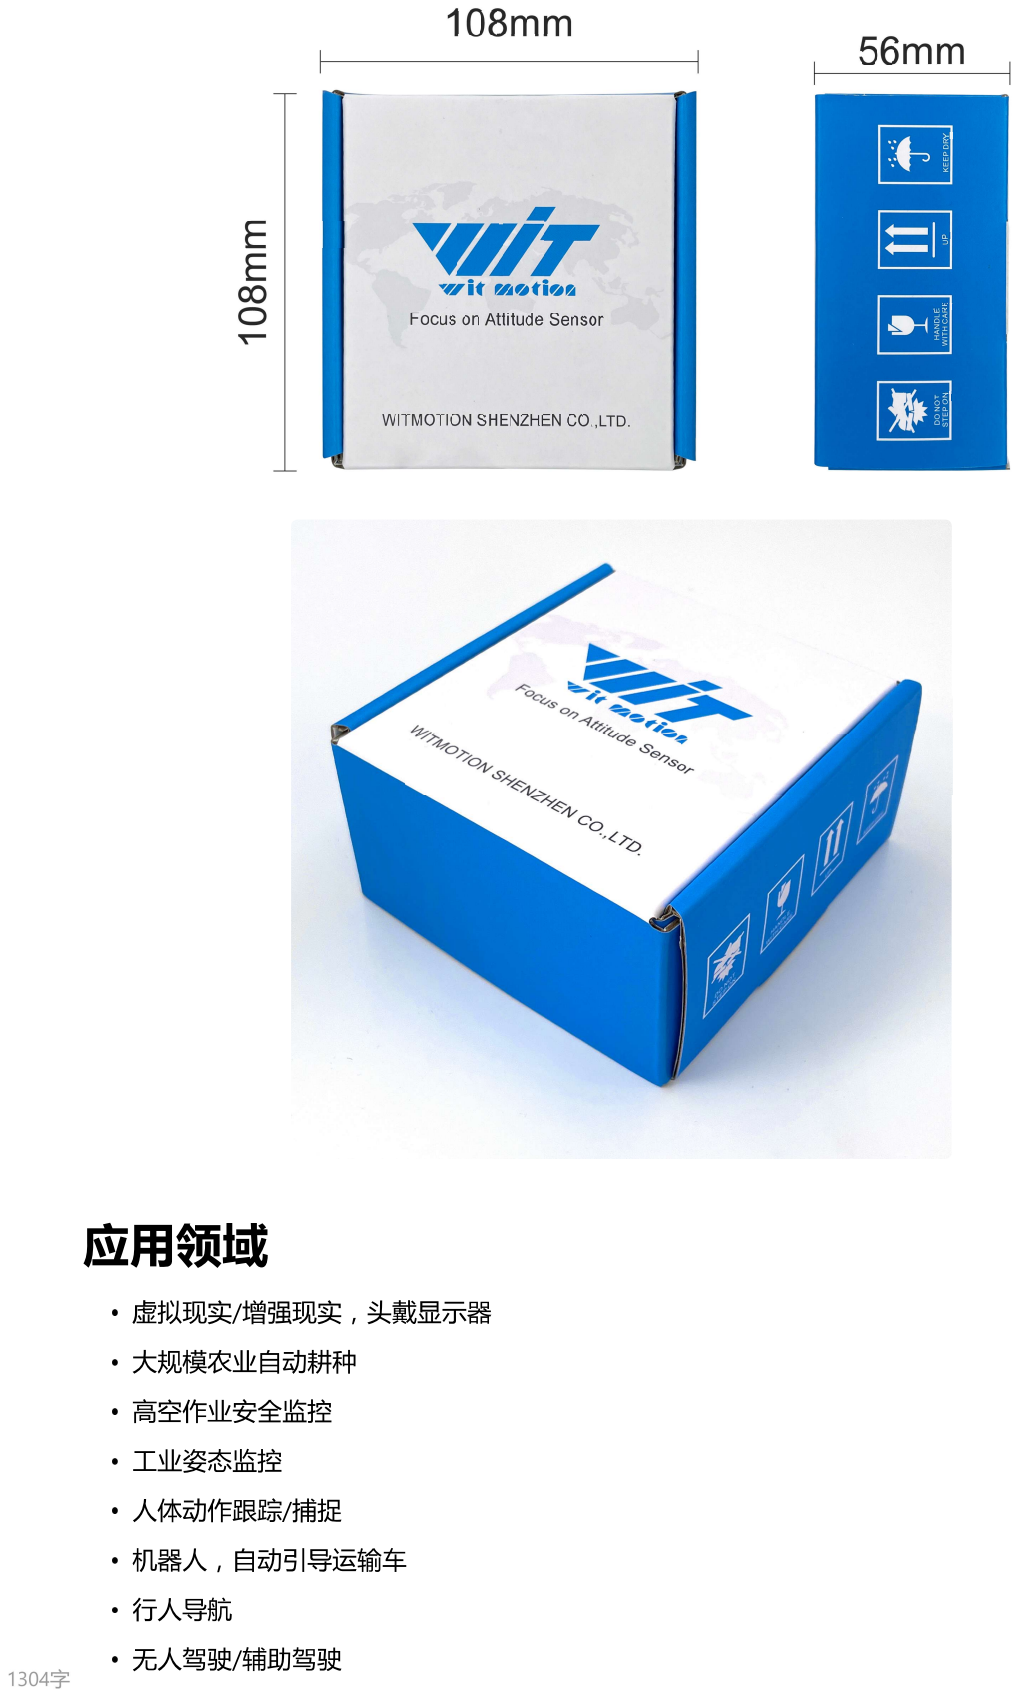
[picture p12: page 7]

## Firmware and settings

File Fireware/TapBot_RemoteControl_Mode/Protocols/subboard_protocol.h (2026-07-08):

/******************** (C) COPYRIGHT 2026 *****************************************
 * @file    subboard_protocol.h
 * @brief   Command definitions between F107 main board and F103 end-effector board.
 * @note        
 * @warning     
 * @license     This project is released under the MIT License.
 *********************************************************************************/
#ifndef __SUBBOARD_PROTOCOL_H
#define __SUBBOARD_PROTOCOL_H

#include "stm32f10x.h"


/*=================================== Enumeration definition =========================*/
/* 0x01-0x7f (main to sub); 0x80-0xff(sub to main) */
typedef enum
{
    SUBBOARD_CMD_HEARTBEAT          = 0x01,
    SUBBOARD_CMD_ESTOP              = 0x02,
    SUBBOARD_CMD_STOP               = 0x03,
    SUBBOARD_CMD_SET_MODE           = 0x04,
    SUBBOARD_CMD_SERVO123_SPEED     = 0x20,
    SUBBOARD_CMD_SERVO123_POSITION  = 0x21,
    SUBBOARD_CMD_AUTO_START         = 0x30,
    SUBBOARD_CMD_AUTO_STOP          = 0x31,
    SUBBOARD_CMD_PUSHROD            = 0x40,

    SUBBOARD_FB_ACK                 = 0x80,
    SUBBOARD_FB_STATE               = 0x81,
    SUBBOARD_FB_SERVO               = 0x82,
    SUBBOARD_FB_ERROR               = 0x83
} subboard_cmd_id_t;



typedef enum
{
    SUBBOARD_MODE_REMOTE_SPEED = 0,
    SUBBOARD_MODE_UPPER_POSITION = 1,
    SUBBOARD_MODE_AUTO = 2,
    SUBBOARD_MODE_ESTOP = 3
} subboard_mode_t;



typedef enum
{
    SUBBOARD_STATE_UNKNOWN = 0xFF,
    SUBBOARD_STATE_IDLE = 0,
    SUBBOARD_STATE_REMOTE = 1,
    SUBBOARD_STATE_UPPER = 2,
    SUBBOARD_STATE_WAIT_OBJECT = 3,
    SUBBOARD_STATE_PUSHROD_EXTEND = 4,
    SUBBOARD_STATE_PRESS_HOLD = 5,
    SUBBOARD_STATE_SERVO_FORWARD = 6,
    SUBBOARD_STATE_SERVO_REVERSE = 7,
    SUBBOARD_STATE_WAIT_OBJECT_CLEAR = 8,
    SUBBOARD_STATE_PUSHROD_RETRACT = 9,
    SUBBOARD_STATE_DONE = 10,
    SUBBOARD_STATE_ERROR = 11,
    SUBBOARD_STATE_ESTOP = 12
} subboard_state_t;

typedef enum
{
    SUBBOARD_ERR_NONE = 0,
    SUBBOARD_ERR_CRC = 1,
    SUBBOARD_ERR_LEN = 2,
    SUBBOARD_ERR_TIMEOUT = 3,
    SUBBOARD_ERR_SENSOR = 4,
    SUBBOARD_ERR_PUSHROD = 5,
    SUBBOARD_ERR_SERVO = 6
} subboard_error_t;



/*================================ Function prototype =======================================*/
/* Receive callback function */
void SubBoardProtocol_OnFrame(u8 cmd_id, const u8 *payload, u8 len);

void SubBoardProtocol_SendHeartbeat(void);
void SubBoardProtocol_SendSetMode(u8 mode);
void SubBoardProtocol_SendServo123Speed(s16 speed0, s16 speed1, s16 speed2);
void SubBoardProtocol_SendServo123Position(s16 pos0, s16 pos1, s16 pos2, u16 run_time, u16 speed);

void SubBoardProtocol_SendAutoStart(u16 forward_ms, u16 reverse_ms, s16 speed);
void SubBoardProtocol_SendAutoStop(void);
void SubBoardProtocol_SendEStop(void);

#endif /* __SUBBOARD_PROTOCOL_H */

/******************* (C) COPYRIGHT 2026 END OF FILE ***************************/

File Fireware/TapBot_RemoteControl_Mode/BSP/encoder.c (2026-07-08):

/******************** (C) COPYRIGHT 2026 *****************************************
 * @file        encoder.c
 * @brief       Absolute encoder readout via CAN bus (CAN1 RX).
 * @note        
 * @warning     
 * @license     This project is released under the MIT License.
 *********************************************************************************/
#include "stm32f10x.h" 
#include "can1.h"
#include "encoder.h"
#include "app_config.h"



/**************************************************************************************/
//编码器CAN默认参数:标准帧,数据帧,默认波特率100K,默认地址0x01
//                 64圈 10bit分辨率（1024）
/**************************************************************************************/

/**************************************************************************************/
//                          指令集格式 
//        字节0   字节1    字节2    字节3    字节4    字节5
//        地址    高四位   参数1    参数2    参数3    参数4
//               参数个数
//                低四位
//                功能码

//                                     指令集
//u8 Encoder_Read_Round[2]        = {0x01, 0x00};                          //读取编码器当前圈数、单圈值
//u8 Encoder_Read_Pos_Speed[2]    = {0x01, 0x01};                          //读取编码器当前位置、转速
//u8 Encoder_Read_Pos_Dirc[2]     = {0x01, 0x09};                          //读取编码器位置、工作方向 编码器位置4个字节，32位无符号数，高字节在前；方向信息1个字节，取值范围1-2

//u8 Encoder_Set_Addr[3]          = {0x01, 0x12, 0x02};                    //设置编码器节点地址，取值范围01-FF
//u8 Encoder_Set_Bund[3]          = {0x01, 0x13, 0x04};                    //设置波特率，取值范围1-5。默认值为5 1:1Mhz\2:500K\3:250K\4:125K\5:100K
//u8 Encoder_Set_Mode[3]          = {0x01, 0x14, 0x02};                    //设置工作模式，取值范围1-2。默认值为1,1:查询模式 2:主动上传(当前位置和转速)
//u8 Encoder_Set_Resp[4]          = {0x01, 0x25, 0x03, 0xE8};              //设置主动上传周期，取值范围1-10000。单位：100us 默认值为10,即10*100=1000us
//u8 Encoder_Set_Zero[3]          = {0x01, 0x16, 0xFF};                    //编码器置零,以当前位置为新的零点。
//u8 Encoder_Set_Zero_Pos[3]      = {0x01, 0x17, 0x02};                    //设置编码器零点取值，取值范围1-2。默认值为1 此指令只对多圈编码器有效 1:中间值 2:0值
//u8 Encoder_Set_Dirc[3]          = {0x01, 0x18, 0x02};                    //设置编码器值递增方向，取值范围1-2。默认值为1 1:顺时针工作值递增2:逆时针工作值递增
//u8 Encoder_Set_Pos[6]           = {0x01, 0x4A, 0x00, 0x00, 0x00, 0x01};  //设置编码器当前位置(测量范围内可设任意值为当前值) 此指令只对多圈编码器有效 取值范围0-0xFFFFFFFF
//u8 Encoder_Set_Speed_Capture[3] = {0x01, 0x1B, 0x0A};                    //设置速度采样周期，取值范围01-C8。 单位：10ms 默认值为0A,即10*10=100ms
/**************************************************************************************/

/**************************************************************************************/
//初始化步骤(一次)：设置ID->设置波特率->设置自动上报模式->零点取0->当前位置置0->设置方向->设置速度采样周期->设置自动上报频率
// 0x01            12,01   13,04(125K)    14,02         17,02     16,FF      18,02     1B,01(10ms)     25,00,64(10ms)
//反馈数据放进数组，通过CAN1打印
//之后注释掉初始化函数
/**************************************************************************************/



/**************************** 全局变量定义 ****************************************/
extern u8 canrxbuf1[8];

u8 Encoder_Set_OneByte[3]  = {0x01, 0x00, 0x00};
u8 Encoder_Set_Resp[4]     = {0x01, 0x25, 0x00, 0x00};
u8 Encoder_Set_Pos[6]      = {0x01, 0x4A, 0x00, 0x00, 0x00, 0x01};
u16 RxRoundBuffer[2]    = {0x00, 0x00};                      

u8 Code[7][2] ={
    {0x12,0x01},         // 设置ID
    {0x13,0x05},         // 设置波特率100K
    {0x14,0x02},         // 设置自动上报模式
    {0x17,0x02},         // 零点取0（多圈编码器有效）
    {0x16,0xFF},         // 当前位置置0
    {0x18,0x02},         // 设置方向:逆时针递增
    {0x1B,0x01}          // 设置速度采样周期10ms
};

static encoder_feedback_t EncoderFeedback = {0, 0, 0U};

#define ENCODER_NODE_ADDR              0x01U
#define ENCODER_POS_SPEED_CODE         0x01U
#define ENCODER_POS_SPEED_PUSH_CODE    0x59U
#define ENCODER_S32_MAX                2147483647LL


/********************************************************************************
 * @name 	Encoder_Set_OneByte_Fun（u8 Code, u8 Obj）
 * @brief   编码器单字节指令设置函数
 * @param   code 功能码（高4位参数个数+低4位功能码）
 *          obj 指令参数（1字节
 * @retval  无
 * @note    CAN发送格式：地址(1)+功能码(1)+参数(1)，共3字节
 ********************************************************************************/
void Encoder_Set_OneByte_Fun(u8 Code, u8 Obj)
{
    Encoder_Set_OneByte[1] = Code;
    Encoder_Set_OneByte[2] = Obj;

    Can1_Send_Msg(Encoder_Set_OneByte,0x00,3);
    swgPrtUx(USART2, "\r\n transmit Ok \r\n");

#if 0 
    while(rxflag)
    {
        if(canrxbuf1[2] == 0x00)
        return;
    }
#endif
}

/********************************************************************************
 * @name 	Encoder_Set_Resp_Fun(u16 RespCode)
 * @brief   设置编码器上传周期
 * @param   resp_code 上传周期（0001-2710，单位：100us）
 * @retval  无
 * @note    CAN发送格式：地址(1)+功能码(1)+参数高8位(1)+参数低8位(1)，共4字节
 ********************************************************************************/
void Encoder_Set_Resp_Fun(u16 RespCode)
{
    Encoder_Set_Resp[2] = (u8)(RespCode >> 8);
    Encoder_Set_Resp[3] = (u8)RespCode;

    Can1_Send_Msg(Encoder_Set_Resp,0x00,4);
    swgPrtUx(USART2, "\r\n transmit Ok \r\n");

#if 0 
    while(rxflag)
    {
        if(canrxbuf1[2] == 0x00)
        return;
    }
#endif
}

/********************************************************************************
 * @name 	Encoder_Set_Pos_Fun(u32 PosCode)
 * @brief   设置编码器当前位置
 * @param   pos_code 当前位置值（32位）
 * @retval  无
 * @note    CAN发送格式：地址(1)+功能码(1)+参数(4)，共6字节
 ********************************************************************************/
void Encoder_Set_Pos_Fun(u32 PosCode)
{
    u32 timeout = ENCODER_CAN_WAIT_TIMEOUT;

    Encoder_Set_Pos[2] = (u8)(PosCode >> 24);
    Encoder_Set_Pos[3] = (u8)(PosCode >> 16);
    Encoder_Set_Pos[4] = (u8)(PosCode >> 8);
    Encoder_Set_Pos[5] = (u8)PosCode;
    canrxbuf1[2] = 0xFFU;
    Can1_Send_Msg(Encoder_Set_Pos,0x00,6);

    while((canrxbuf1[2] != 0x00U) && (timeout > 0U))
    {
        timeout--;
    }
}

/********************************************************************************
 * @name 	Encoder_Read_Round_Fun(void)
 * @brief   读取编码器当前圈数、单圈值
 * @param   无
 * @retval  无
 * @note    发送读取指令后，从CAN接收缓冲区解析圈数（2字节）和单圈值（2字节）
 *              圈数2个字节，16 位无符号数，高字节在前  (单圈编码器固定为0x00 0x00)；
 *              单圈值2个字节，16 位无符号数，高字节在前；
 ********************************************************************************/
void Encoder_Read_Round_Fun(void)
{
    u8 Encoder_Read_Round[2] = {0x01, 0x00};
    Can1_Send_Msg(Encoder_Read_Round,0x00,2);
    
    for(u8 i =0; i < 2; i++)
    {
        RxRoundBuffer[i] = (u16)((u16)canrxbuf1[2*i+2]<<8 | (u16)canrxbuf1[2*i+3]);
    }
}
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

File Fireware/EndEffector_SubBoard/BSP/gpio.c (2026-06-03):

#include "gpio.h"

#define PHOTO_GPIO_RCC       RCC_APB2Periph_GPIOA
#define PHOTO_GPIO_PORT      GPIOA
#define PHOTO_GPIO_PIN       GPIO_Pin_0
#define PUSH_GPIO_RCC        RCC_APB2Periph_GPIOB
#define PUSH_GPIO_PORT       GPIOB
#define PUSH_EXTEND_PIN      GPIO_Pin_0
#define PUSH_RETRACT_PIN     GPIO_Pin_1

void EndGpio_Init(void)
{
    GPIO_InitTypeDef gpio;

    RCC_APB2PeriphClockCmd(PHOTO_GPIO_RCC | PUSH_GPIO_RCC, ENABLE);

    gpio.GPIO_Pin = PHOTO_GPIO_PIN;
    gpio.GPIO_Mode = GPIO_Mode_IPU;
    gpio.GPIO_Speed = GPIO_Speed_50MHz;
    GPIO_Init(PHOTO_GPIO_PORT, &gpio);

    gpio.GPIO_Pin = PUSH_EXTEND_PIN | PUSH_RETRACT_PIN;
    gpio.GPIO_Mode = GPIO_Mode_Out_PP;
    gpio.GPIO_Speed = GPIO_Speed_50MHz;
    GPIO_Init(PUSH_GPIO_PORT, &gpio);
    EndGpio_PushrodOff();
}

u8 EndGpio_ObjectDetected(void)
{
    return (GPIO_ReadInputDataBit(PHOTO_GPIO_PORT, PHOTO_GPIO_PIN) == Bit_RESET) ? 1U : 0U;
}

void EndGpio_PushrodExtendOn(void)
{
    GPIO_SetBits(PUSH_GPIO_PORT, PUSH_EXTEND_PIN);
    GPIO_ResetBits(PUSH_GPIO_PORT, PUSH_RETRACT_PIN);
}

void EndGpio_PushrodRetractOn(void)
{
    GPIO_ResetBits(PUSH_GPIO_PORT, PUSH_EXTEND_PIN);
    GPIO_SetBits(PUSH_GPIO_PORT, PUSH_RETRACT_PIN);
}

void EndGpio_PushrodOff(void)
{
    GPIO_ResetBits(PUSH_GPIO_PORT, PUSH_EXTEND_PIN | PUSH_RETRACT_PIN);
}

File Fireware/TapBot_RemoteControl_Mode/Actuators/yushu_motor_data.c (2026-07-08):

/******************** (C) COPYRIGHT 2026 *****************************************
  * @file        yushu_motor_data.c
  * @brief       Unitree M8010 actuator command generation.
  * @note        
  * @warning     
  * @license     This project is released under the MIT License.
 *********************************************************************************/
#include "yushu_motor_data.h"
#include "control_math.h"
#include "control_dispatcher.h"
#include "app_config.h"
#include "encoder.h"

/**********************************  Global Variables ********************************************/
float YushuSpeed = 0.0f;


float Gear_Speed_Arr[2][3] =
{
    { YUSHU_GEAR_IN_BACK,   YUSHU_GEAR_IN_MID,     YUSHU_GEAR_IN_FORWARD },
    { YUSHU_SPEED_OUT_BACK, YUSHU_SPEED_OUT_MID,   YUSHU_SPEED_OUT_FORWARD }
};


/*   PID struction    */
typedef struct
{
    float integral;
    float prev_error;
    u8 initialized;
} yushu_pid_state_t;

static yushu_pid_state_t YushuLengthPid = {0.0f, 0.0f, 0U};



static s16 Yushu_ScaleFloat(float value, float scale)
{
    if(value >= 0.0f)
    {
        return (s16)(value * scale + 0.5f);
    }
    return (s16)(value * scale - 0.5f);
}


//  init state  to  stop
static void YushuMotor_InitCmdOnce(void)
{
    cmd.id = YUSHU_M8010_ID;
    cmd.mode = YUSHU_M8010_MODE_STOP;
    cmd.T = 0.0f;
    cmd.W = 0.0f;
    cmd.Pos = 0.0f;
    cmd.K_P = 0.0f;
    cmd.K_W = 0.0f;
}



/**********************************  PID ********************************************/
static void YushuMotor_ResetLengthPid(void)
{
    YushuLengthPid.integral = 0.0f;
    YushuLengthPid.prev_error = 0.0f;
    YushuLengthPid.initialized = 0U;
}

static float YushuMotor_ClampFloat(float value, float min_value, float max_value)
{
    if(value < min_value)
    {
        return min_value;
    }
    if(value > max_value)
    {
        return max_value;
    }
    return value;
}

static float YushuMotor_LengthPidSpeed(s32 target_length_mm, float max_speed)
{
    const encoder_feedback_t *encoder = Encoder_GetFeedback();
    float error;
    float derivative = 0.0f;
    float output;

    if((encoder->valid == 0U) || (max_speed <= 0.0f))
    {
        YushuMotor_ResetLengthPid();
        return 0.0f;
    }

    error = (float)(target_length_mm - encoder->length_mm);
    if((error >= -((float)YUSHU_LENGTH_TOL_MM)) && (error <= (float)YUSHU_LENGTH_TOL_MM))
    {
        YushuMotor_ResetLengthPid();
        return 0.0f;
    }

    if(YushuLengthPid.initialized != 0U)
    {
        derivative = (error - YushuLengthPid.prev_error) / YUSHU_LENGTH_PID_DT_S;
    }
    else
    {
        YushuLengthPid.initialized = 1U;
    }

    YushuLengthPid.integral += error * YUSHU_LENGTH_PID_DT_S;
    YushuLengthPid.integral = YushuMotor_ClampFloat(YushuLengthPid.integral,
                                                    -YUSHU_LENGTH_PID_I_LIMIT,
                                                    YUSHU_LENGTH_PID_I_LIMIT);
    YushuLengthPid.prev_error = error;

    output = (YUSHU_LENGTH_PID_KP * error) +
             (YUSHU_LENGTH_PID_KI * YushuLengthPid.integral) +
             (YUSHU_LENGTH_PID_KD * derivative);

    return YushuMotor_ClampFloat(output, -max_speed, max_speed);
}


/********************************** MExternal interface functions ********************************************/

void YushuMotor_SendControl(void)
{
#if YUSHU_M8010_USE_CAN
    u8 can_data[8];
    s16 speed_cmd = Yushu_ScaleFloat(cmd.W, 10.0f);
    s16 torque_cmd = Yushu_ScaleFloat(cmd.T, 100.0f);
    s16 kw_cmd = Yushu_ScaleFloat(cmd.K_W, 1000.0f);

    can_data[0] = LBT(speed_cmd);
    can_data[1] = HBT(speed_cmd);
    can_data[2] = LBT(torque_cmd);
    can_data[3] = HBT(torque_cmd);
    can_data[4] = LBT(kw_cmd);
    can_data[5] = HBT(kw_cmd);
    can_data[6] = (u8)cmd.mode;
    can_data[7] = (u8)cmd.id;
    Can1_Send_Msg(can_data, YUSHU_M8010_CAN_TX_ID, 8U);
#else
    USART1_DMA_send((uint8_t *)&cmd, sizeof(cmd.motor_send_data));
#endif
}

void SendYushuMotorDataFun(void)
{
}

void SendYushuMotor_MoveCmd(u8 MoveFlag)
{
    static MOTOR_send *pData;
    static u8 FirstFlag = 1U;

    if(FirstFlag == 1U)
    {
        YushuMotor_InitCmdOnce();
        FirstFlag = 0U;
    }

    switch(MoveFlag)
    {
        case YUSHU_SHORTEN:
            cmd.mode = YUSHU_M8010_MODE_RUN;
            cmd.T = 0.0f;
            cmd.W = 20.0f;
            cmd.K_W = 0.05f;
            break;

        case YUSHU_STRETCH:
            cmd.mode = YUSHU_M8010_MODE_RUN;
            cmd.T = 0.0f;
            cmd.W = -20.0f;
            cmd.K_W = 0.05f;
            break;

        case YUSHU_STOP:
        default:
            cmd.mode = YUSHU_M8010_MODE_STOP;
            cmd.T = 0.0f;
            cmd.W = 0.0f;
            cmd.K_W = 0.0f;
            break;
    }

    pData = &cmd;
    modify_data(pData);
    YushuMotor_SendControl();
}

void RmtYushuMotor_MoveCmd(void)
{
    static s8 Rmt_Y2_FNR = 0;
    static s8 Rmt_Y2_FNR_Old = 0;

    if(RmtGearValue > 10.0f)
    {
        Rmt_Y2_FNR = 1;
    }
    else if(RmtGearValue < -10.0f)
    {
        Rmt_Y2_FNR = -1;
    }
    else
    {
        Rmt_Y2_FNR = 0;
    }

    if(LIMIT_SWITCH_IN != 0)
    {
        if(((Rmt_Y2_FNR_Old == 0) && (Rmt_Y2_FNR == 1)) ||
            ((Rmt_Y2_FNR_Old == -1) && (Rmt_Y2_FNR == 1)))
        {
            SW_CLUTCH(ON);
            SendYushuMotor_MoveCmd(YUSHU_STRETCH);
        }
        else if(((Rmt_Y2_FNR_Old == 0) && (Rmt_Y2_FNR == -1)) ||
                ((Rmt_Y2_FNR_Old == 1) && (Rmt_Y2_FNR == -1)))
        {
            SW_CLUTCH(OFF);
            SendYushuMotor_MoveCmd(YUSHU_SHORTEN);
        }
        else if(((Rmt_Y2_FNR_Old == 1) && (Rmt_Y2_FNR == 0)) ||
                ((Rmt_Y2_FNR_Old == -1) && (Rmt_Y2_FNR == 0)))
        {
            SendYushuMotor_MoveCmd(YUSHU_STOP);
        }
        Rmt_Y2_FNR_Old = Rmt_Y2_FNR;
    }
    else
    {
        SendYushuMotor_MoveCmd(YUSHU_STOP);
    }
}
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

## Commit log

2026-04-07 confirm general framework
2026-04-10 [clomol]: Establish the main framework and fill in the details
    [List_SlipRing.xls, TapBOT_V1.xls]
2026-06-02 STM32 first fullfill
2026-06-03 change all due to something bad
    [TapBot_TCP_UP.xlsx, 下位机通讯协议_飞特手册风格版_含例帧解析.xlsx]
2026-07-08 new update
    [HWT901-CAN.SLDPRT, HWT901-CAN.stp, IMU_01_bracket.SLDPRT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]
